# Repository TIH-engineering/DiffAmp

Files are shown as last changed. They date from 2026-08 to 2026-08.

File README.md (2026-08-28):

# DiffAmp






## 🔌 Leiterplattenbeschreibung

Die Leiterplatte **DiffAmp** dient zur praktischen Untersuchung von **Differenzverstärkern**. Sie ermöglicht den Vergleich einer diskret mit Transistoren aufgebauten Differenzverstärkerstufe mit einem Differenzverstärker auf Basis eines **Operationsverstärkers**.

Die Leiterplatte enthält zwei unterschiedliche Schaltungsvarianten:

- **Differenzverstärker mit zwei Bipolartransistoren**
- **Differenzverstärker mit Operationsverstärker (Subtrahierer)**

Der diskrete Differenzverstärker kann über Jumper in unterschiedlichen Betriebsarten betrieben werden. Die gemeinsame Emitterbeschaltung der beiden Transistoren kann wahlweise mit einem **Emitterwiderstand** oder mit einer **Stromquelle** realisiert werden. Dadurch lässt sich der Einfluss der Stromquellenschaltung auf das Verhalten des Differenzverstärkers praktisch untersuchen.

Zusätzliche Jumper ermöglichen unterschiedliche Messkonfigurationen zur Bestimmung der

- **Gegentaktverstärkung**
- **Gleichtaktverstärkung**

Damit können aus den Messwerten auch die Unterschiede zwischen Gegentakt- und Gleichtaktansteuerung sowie die **Gleichtaktunterdrückung** des Differenzverstärkers untersucht werden.

Als Vergleichsschaltung ist zusätzlich ein Differenzverstärker mit einem **LM358-Operationsverstärker** aufgebaut. Dieser arbeitet als Subtrahierer und bildet die Differenz der beiden Eingangssignale `In1` und `In2`.

Die verschiedenen Ausgangssignale der Schaltungen stehen an separaten Anschlüssen zur Verfügung und können beispielsweise mit einem **Oszilloskop** vermessen und miteinander verglichen werden.

> **Einsatzgebiet:** Laborübungen und Unterricht zu Differenzverstärkern, Operationsverstärkern, Gegentakt- und Gleichtaktverstärkung sowie Gleichtaktunterdrückung

---

## 📥 Downloads

| Datei | Beschreibung |
|---|---|
| 📄 [Schaltplan (PDF)](../../releases/latest/download/schematic.pdf) | Schaltplan der Leiterplatte |
| 🖨️ [Leiterplatte (PDF)](../../releases/latest/download/pcb.pdf) | Leiterplattenansicht als PDF |
| 🔩 [Bohrplan (PDF)](../../releases/latest/download/drill.pdf) | Bohrdaten / Bohrplan |
| 📋 [Stückliste (Excel)](../../releases/latest/download/bom.xlsx) | Bill of Materials |
| 🌐 [Interactive BOM](../../releases/latest/download/ibom.html) | Interaktive Bestückungsansicht |
| 📦 [Fertigungsdaten](../../releases/latest/download/kicad.zip) | Gerber- und Bohrdaten |
| 🧊 [STEP-Modell](../../releases/latest/download/pcb.step) | 3D-Modell der Leiterplatte |

Die Dateien werden automatisch durch den Release-Workflow erzeugt.

---

## 🖥️ Leiterplatte

### Vorschau

| Oberseite | Unterseite |
|:---:|:---:|
| PCB Top | PCB Bottom |

### Oberseite

PCB Top

### Unterseite

PCB Bottom

---

## ℹ️ Projektinformationen

| Eigenschaft | Wert |
|---|---|
| **Projekt** | DiffAmp |
| **Software** | KiCad 10 |
| **Repository** | github.com/TIH-engineering/DiffAmp |
| **Autor** | TIH |
| **Lizenz** | CC BY-NC-SA 4.0 |

---

## 🗂️ Repository-Struktur

```text
.
├── .github/
│   └── workflows/       # GitHub Actions
├── .kibot/              # KiBot-Konfiguration
├── pcb/
│   ├── lib/             # Projektspezifische Bibliotheken
│   └── ...              # KiCad-Projektdateien
├── .gitignore
├── LICENSE
└── README.md

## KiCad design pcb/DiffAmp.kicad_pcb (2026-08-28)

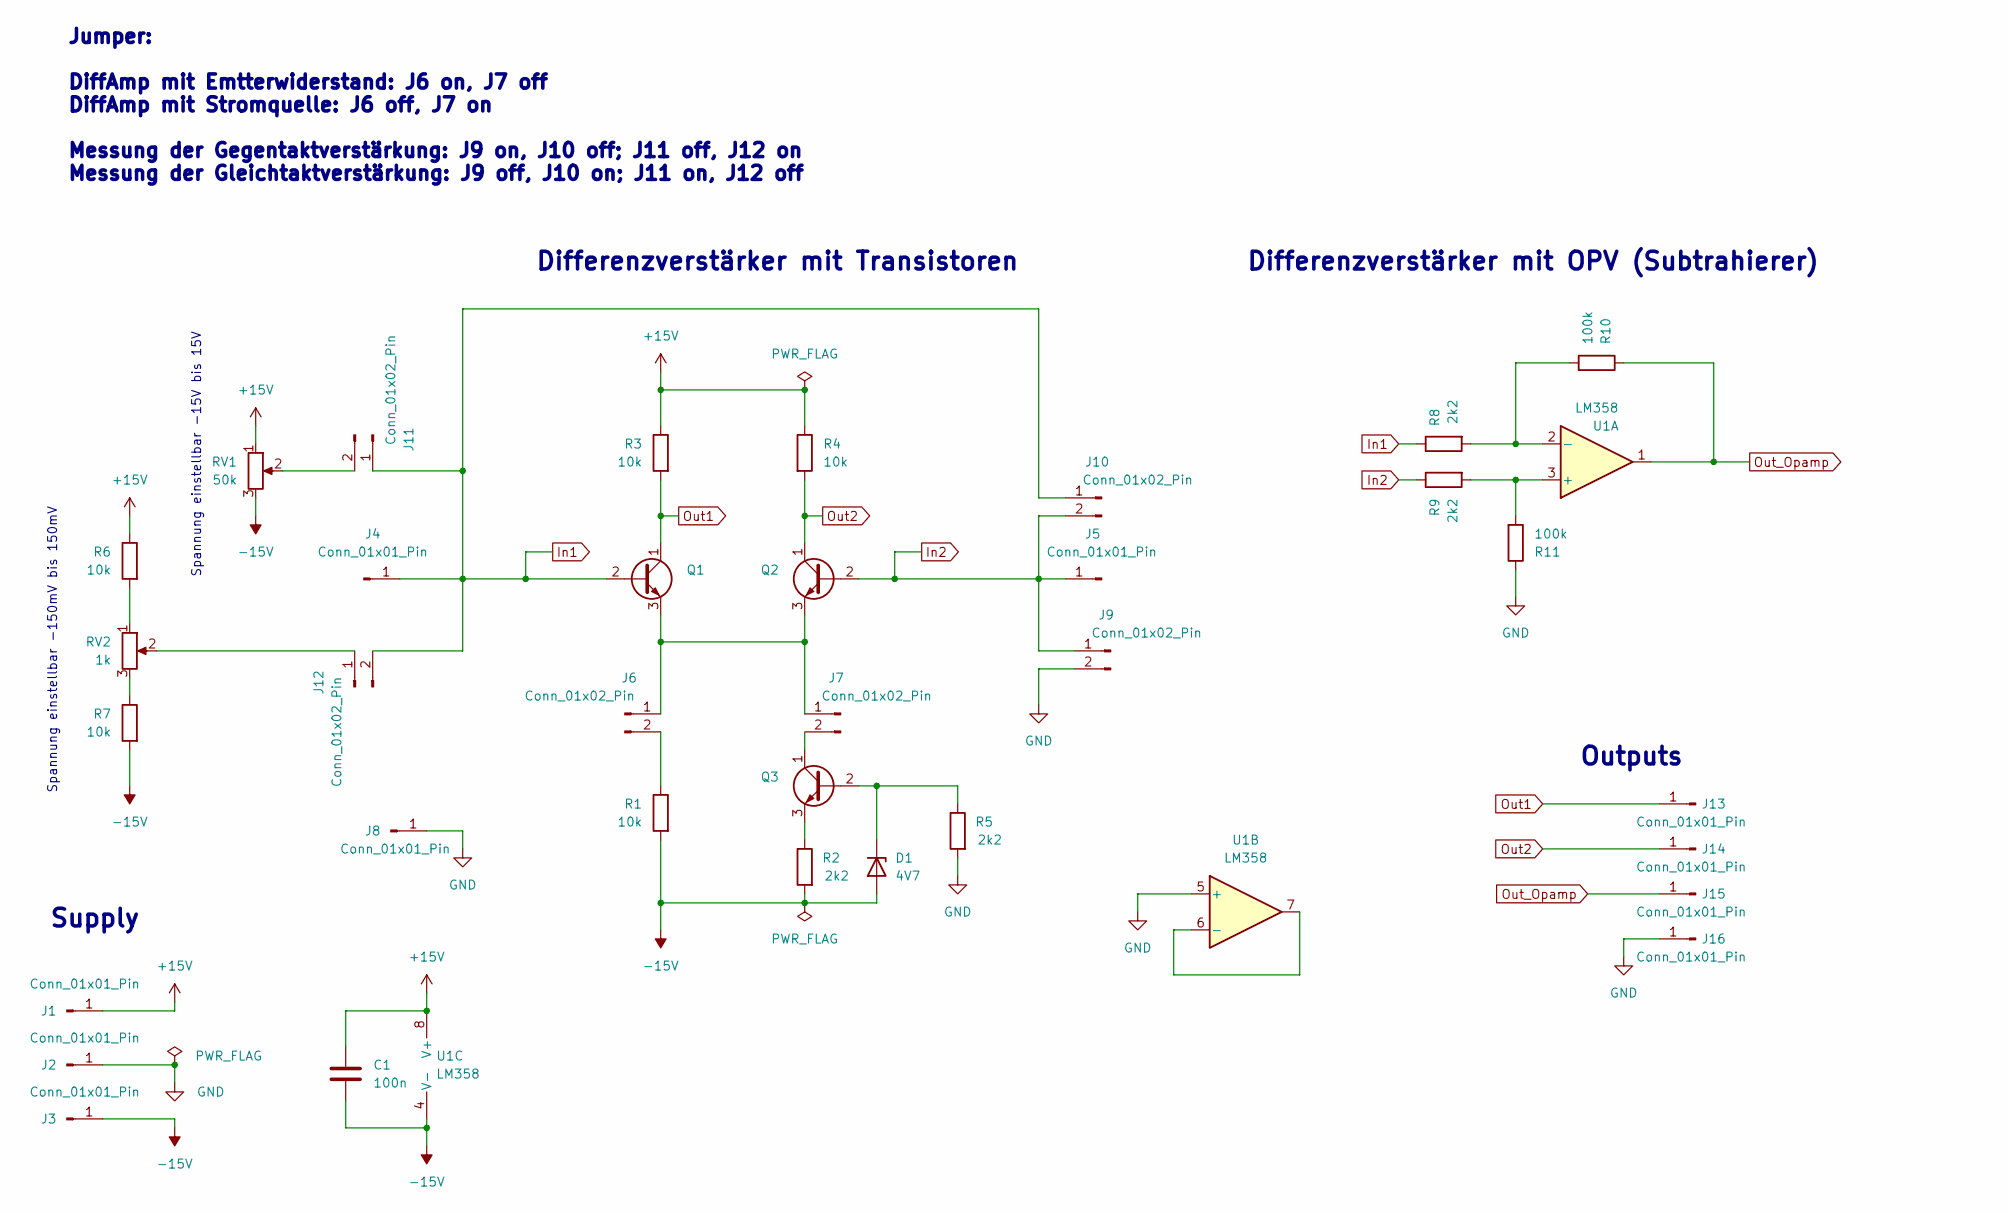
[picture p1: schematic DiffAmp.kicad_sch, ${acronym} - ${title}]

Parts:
C1: 100n; C_Disc_D3.8mm_W2.6mm_P2.50mm
D1: 4V7; D_A-405_P10.16mm_Horizontal
J1, J2, J3, J4, J5, J8, J13, J14, J15, J16: Conn_01x01_Pin; PinHeader_1x01_P2.54mm_Vertical
J6, J7, J9, J10, J11, J12: Conn_01x02_Pin; PinHeader_1x02_P2.54mm_Vertical
Q1, Q2, Q3: BC547; TO-92_Inline_Wide
R1, R3, R4, R6, R7: 10k; R_Axial_DIN0207_L6.3mm_D2.5mm_P10.16mm_Horizontal
R2, R5, R8, R9: 2k2; R_Axial_DIN0207_L6.3mm_D2.5mm_P10.16mm_Horizontal
R10, R11: 100k; R_Axial_DIN0207_L6.3mm_D2.5mm_P10.16mm_Horizontal
RV1: 50k; Potentiometer_Bourns_3005_Horizontal
RV2: 1k; Potentiometer_Bourns_3005_Horizontal
U1: LM358; DIP-8_W7.62mm

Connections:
+15V: C1.1, J1.1 (Pin_1_1), R3.1, R4.1, R6.1, RV1.1, U1.8 (V+)
-15V: C1.2, D1.2 (A), J3.1 (Pin_1_1), R1.2, R2.2, R7.2, RV1.3, U1.4 (V-)
GND: J2.1 (Pin_1_1), J8.1 (Pin_1_1), J9.2, J16.1 (Pin_1_1), R5.2, R11.1, U1.5 (+)
In1: J4.1 (Pin_1_1), J10.1, J11.1, J12.2, Q1.2 (B), R8.1
In2: J5.1 (Pin_1_1), J9.1, J10.2, Q2.2 (B), R9.1
unnamed: D1.1 (K), Q3.2 (B), R5.1
unnamed: J6.1, J7.1, Q1.3 (E), Q2.3 (E)
unnamed: J6.2, R1.1
unnamed: J7.2, Q3.1 (C)
unnamed: J11.2, RV1.2
unnamed: J12.1, RV2.2
unnamed: Q3.3 (E), R2.1
unnamed: R6.2, RV2.1
unnamed: R7.1, RV2.3
unnamed: R9.2, R11.2, U1.3 (+)
unnamed: R8.2, R10.2, U1.2 (-)
unnamed: U1.6 (-), U1.7
Out1: J13.1 (Pin_1_1), Q1.1 (C), R3.2
Out2: J14.1 (Pin_1_1), Q2.1 (C), R4.2
Out_Opamp: J15.1 (Pin_1_1), R10.1, U1.1

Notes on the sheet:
Spannung einstellbar -15V bis 15V
Supply
Outputs
Spannung einstellbar -150mV bis 150mV
Jumper: DiffAmp mit Emtterwiderstand: J6 on, J7 off DiffAmp mit Stromquelle: J6 off, J7 on Messung der Gegentaktverstärkung: J9 on, J10 off; J11 off, J12 on Messung der Gleichtaktverstärkung: J9 off, J10 on; J11 on, J12 off
Differenzverstärker mit Transistoren
Differenzverstärker mit OPV (Subtrahierer)

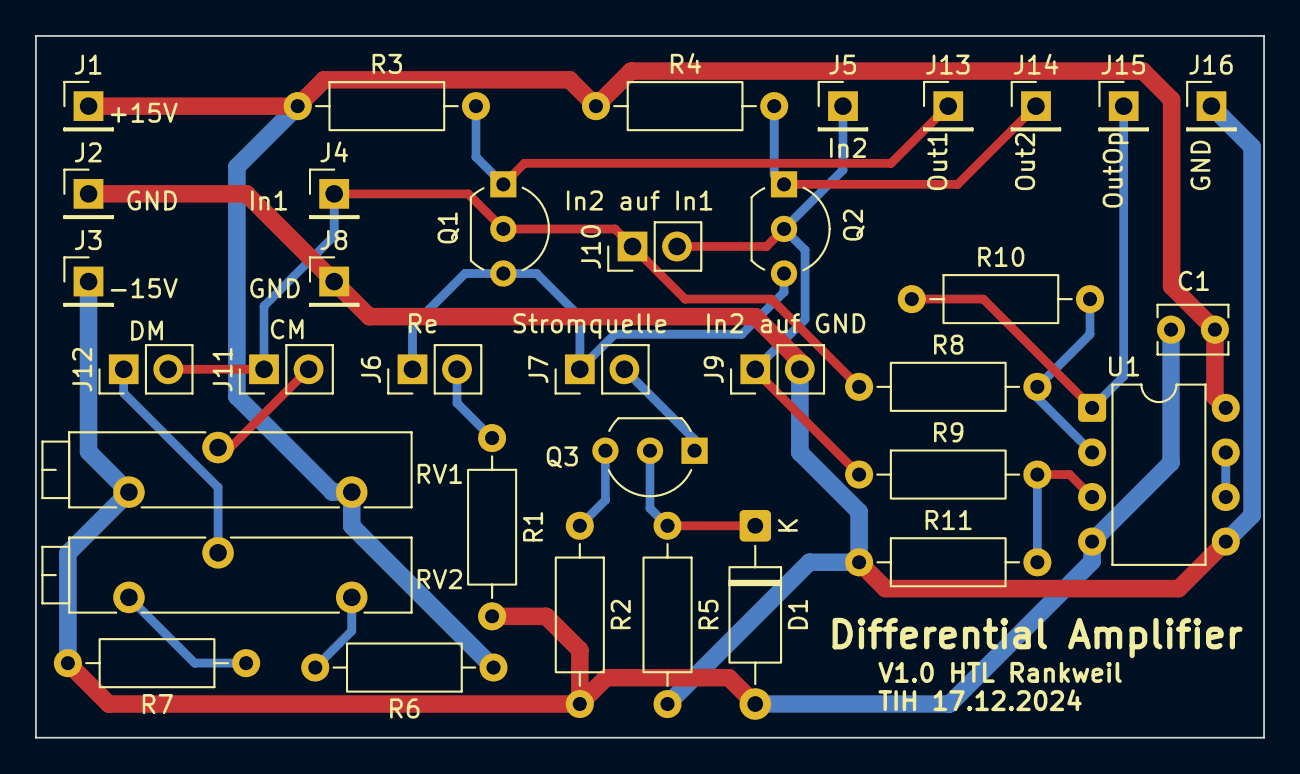
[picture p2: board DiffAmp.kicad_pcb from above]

Board: 2 copper layers, 70.0 x 40.0 mm, 35 parts (0 on the bottom side), 20 nets.

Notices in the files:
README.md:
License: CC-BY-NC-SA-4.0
